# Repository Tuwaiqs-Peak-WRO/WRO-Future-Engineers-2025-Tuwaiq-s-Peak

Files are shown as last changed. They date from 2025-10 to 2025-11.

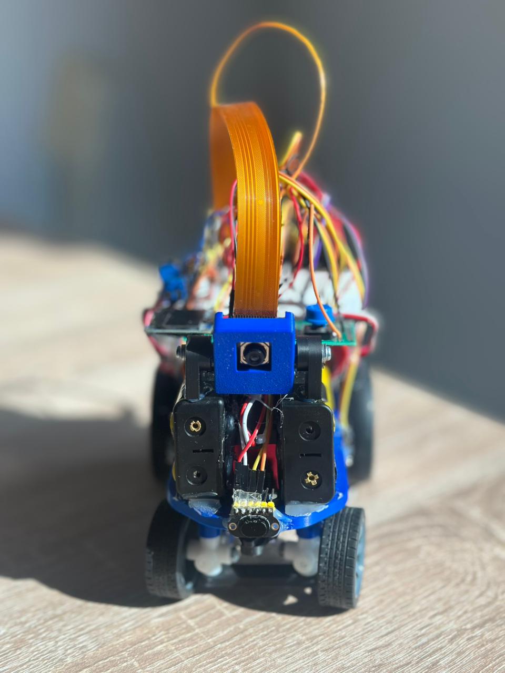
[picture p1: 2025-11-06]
Robot pictures/Robot Front.jpeg

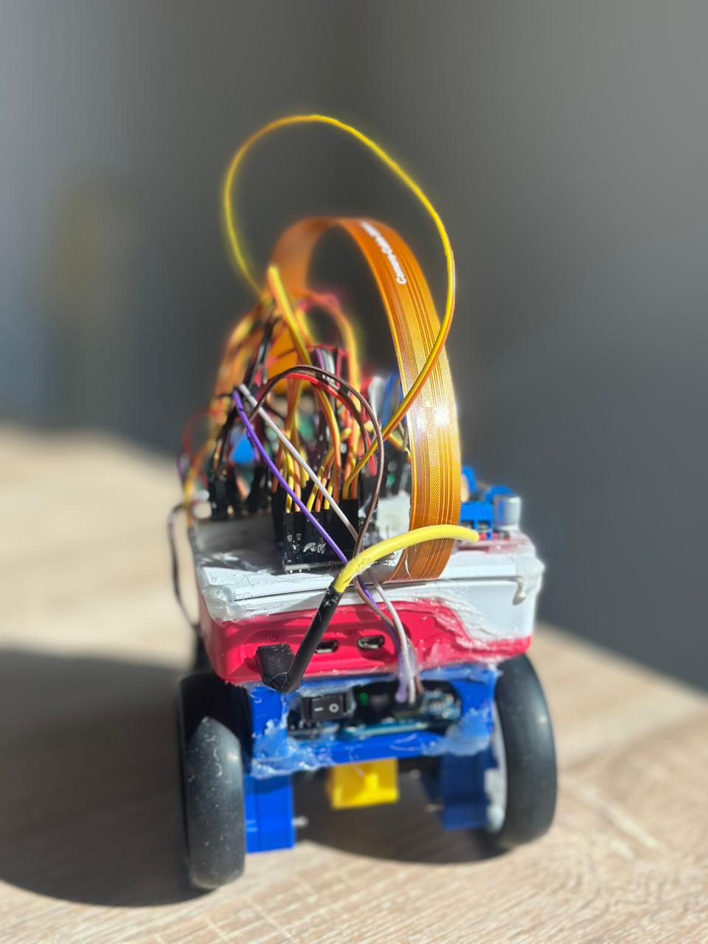
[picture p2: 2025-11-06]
Robot pictures/Robot Back.jpeg

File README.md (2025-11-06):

# Tuwaiqy – Autonomous Robot  
### by Team Tuwaiq’s Peak

WhatsApp Image 2025-10-19 at 17 24 52_02bfc6a8

---

## Team Members  
| Name | Role | Picture |
|---|---|---|
| Reda Mohammed Albin Ahmed| Coder, Strategic Designer | WhatsApp Image 2025-10-23 at 17 48 36_bcb1500e |
| Ibrahim Alangari | 3D Designer, Hardware Engineer | WhatsApp Image 2025-10-23 at 17 48 36_722a9d41 |

---

## Challenge Overview  
**Competition:** WRO Future Engineers  
**Goal:** Build a small autonomous car that can perceive, decide, and navigate without human input.  

### Objectives
- Lane keeping and path following  
- Traffic logic  
- Obstacle handling  
- Parking  

---

## System Overview  
Tuwaiqy uses a hybrid navigation and obstacle management system combining computer vision and Time-of-Flight (ToF) distance sensing.  
The camera provides visual awareness for lane and path detection, while the ToF sensor provides short-range precision distance data.  
Together, they allow the robot to follow the track, detect obstacles, and navigate autonomously in real time.  

---

## Hardware Components  

### 1. Raspberry Pi 5 


**Processor:** 64-bit Quad-core ARM Cortex-A76 @ 2.4 GHz  

**GPU:** VideoCore VII (dual 4K support)  

**Memory:** 8 GB LPDDR4X  

**Storage:** 32 GB microSD  

**Networking:** Gigabit Ethernet, Wi-Fi 5, Bluetooth 5.0  

**Ports:** 2 × USB 3.0, 2 × USB 2.0, 40-pin GPIO  

**Camera Interface:** 2 × CSI-2  

**Display:** 2 × micro-HDMI (4K 60 fps)  

**Power:** USB-C 5 V / 5 A  

**OS:** Raspberry Pi OS (64-bit)  

**Dimensions:** 85.6 × 56.5 × 17 mm (~50 g)  

**Advantages**
- High performance for AI and computer vision  
- Full Linux + Python environment  
- Compact and efficient  

**Disadvantages**
- Requires active cooling  
- Needs a stable 5 V / 5 A power source  

---

### 2. Raspberry Pi Active Cooler  
Screenshot 1447-05-04 at 10 58 43 AM

Compact fan-based cooler mounted via GPIO to prevent thermal throttling during high CPU usage.  

---

### 3. Gyroscope (BNO085)  
Screenshot 1447-05-04 at 10 59 45 AM

**Type:** 9-axis IMU (accelerometer + gyroscope + magnetometer)  

**Interface:** I²C / SPI  

**Voltage:** 3.3–5 V  

**Role:** Provides orientation and motion feedback for PID and steering control.  

---

### 4. OLED Display (0.96 in) 
Screenshot 1447-05-04 at 11 00 40 AM

**Resolution:** 128 × 64 pixels  

**Interface:** I²C / SPI  

**Voltage:** 3.3–5 V  

**Role:** Displays system information and debugging data.  

---

### 5. Push Button  
Screenshot 1447-05-04 at 11 03 05 AM

**Type:** Momentary (Normally Open)  

**Role:** Used for manual start or reset input.  

---

### 6. Raspberry Pi Camera Module 3 (Wide)  
Screenshot 1447-05-04 at 11 04 52 AM

**Resolution:** 12 MP  

**Video:** 1080p @ 60 fps  

**Interface:** CSI  

**Lens:** Fixed-focus wide-angle  

**Role:** Main vision system for lane detection and path recognition.  

---

### 7. Step-Up Converter (XL6019)  
Screenshot 1447-05-04 at 11 10 43 AM

**Input:** 5–32 V → **Output:** 5–35 V (adjustable)

**Output Current:** Up to 4 A

**Role:** Boosts voltage for servos or higher-load components.  

---

### 8. DC-DC Step Down Converter (Mini560)
Screenshot 1447-05-04 at 11 10 43 AM

**Output:** 3.3 / 5 / 9 / 12 V (adjustable)  

**Current:** Up to 8 A (>90 % efficiency)  

**Weight:** 7 g  

**Role:** Provides 5V power for the Raspberry Pi and logic circuits.  

---

### 9. (2x) NL1836HP battery
Screenshot 1447-05-04 at 10 59 45 AM

**Voltage:** 3.6 V

**Capacity:** 3600 mAh

**Discharge Rate:** 8 A (continuous)

**Type:** 18650 Li-ion rechargeable cell

**Role:** Provides high Current to power our motor

---

### 10. (2x) NITECORE NL1836 Battery
Screenshot 1447-05-04 at 10 59 45 AM

**Voltage:** 3.6 V 

**Capacity:** 3,600 mAh 

**Continuous Discharge Current:** 3 A 

**Role:** Reliable power source for the Raspperry pi 5

---

### 11. Servo Motor (40 kg·cm)  
Screenshot 1447-05-04 at 11 15 58 AM

**Voltage:** 6–12 V  

**Range:** 180°  

**Role:** Controls the steering of the front wheels.  

---

### 12. Servo Motor Driver (PCA9685PW)  
Screenshot 1447-05-04 at 11 17 08 AM

**Channels:** 16  

**Interface:** I²C  

**Voltage:** 5 V  

**Role:** Controls the steering servo and other PWM-based actuators.  

---

### 13. DC Motor with Encoder (620 RPM)  


**Voltage:** 12 V  

**Feedback:** Encoder output for speed monitoring  

**Role:** Rear-wheel drive and speed feedback for closed-loop control.  

---

### 14. IBT-4 DC Motor Driver 
Screenshot 1447-05-04 at 11 21 07 AM

**Voltage:** 5–36 V  

**Current:** Up to 43 A peak  

**Control:** PWM  

**Role:** Drives high-torque DC motors for movement.  

---

### 15. (2x) TOF200C-VL53L0X  
Screenshot 1447-05-04 at 11 22 43 AM

**Range:** Up to 2 m  

**Accuracy:** ±3 %  

**Interface:** I²C  

**Voltage:** 3.3V 

**Role:** Provides short-range distance on the right and on the left sides of the robot

---
### 16. TOF400C-VL53L1X
Screenshot 1447-05-04 at 11 22 43 AM

**Range:** Up to 4 m  

**Accuracy:** ±3 %  

**Interface:** I²C  

**Voltage:** 3.3V

**Role:** Provides long-range distance measurements for front obstacle detection and navigation.

---

### 17. TCA9548A 1-To-8 I2C 8 -Way Multi-Channel Expansion Board IIC Module Development Board
Screenshot 1447-05-04 at 11 22 43 AM

**Name:** TCA9548A 1-to-8 I²C Multiplexer

**Interface:** I²C  

**Voltage:** 1.65V – 5.5V

**Address Pins:** A0, A1, A2 (allow up to 8 multiplexers on the same I²C bus)

**Role:** Enables the use of multiple ToF sensors with identical I²C addresses for multi-directional distance measurement on our Robot.

---

## System Integration  

**Power**
- Nihewo 7.4 V battery powers the system.  
- Mini560 converter outputs regulated 5 V for logic and control circuits.  
- XL6019 step-up converter provides higher voltage for servo operation.  

**Control**
- Raspberry Pi 5 handles computer vision and sensor fusion.  
- BNO085 IMU provides stabilization data.  
- TOF sensor measures distance for real-time obstacle management.  

**Motion**
- IBT-4 driver powers the rear DC motors.  
- PCA9685 controls the front steering servo.  
- Encoders provide feedback for accurate speed control.  

**Feedback**
- OLED display shows live data and status.  
- RGB LED and Buzzer provide visual and audio feedback.  
- Push Button allows manual start or reset.  

---

## System Flow  

```text
Camera + TOF Sensor
        ↓
    Raspberry Pi 5
        ↓
 PCA9685 → Servo (Steering)
 IBT-4 → DC Motors (Drive)
        ↓
 OLED + RGB LED + Buzzer (Feedback)
        ↓
 Power Distribution → Mini560 / XL6019 from 7.4 V Battery

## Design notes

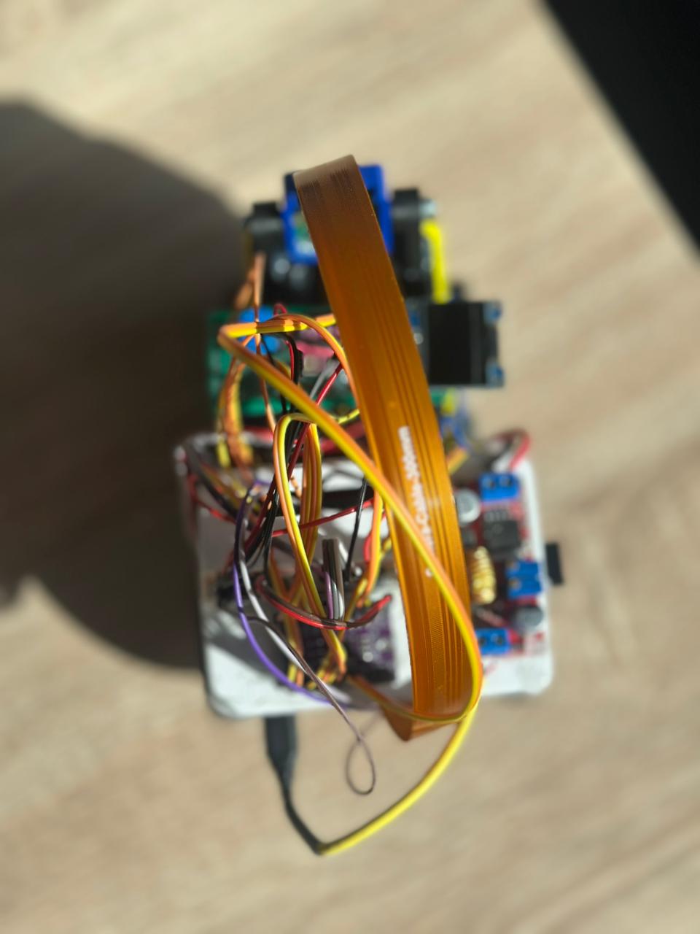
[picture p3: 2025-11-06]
Robot pictures/Robot Top.jpeg

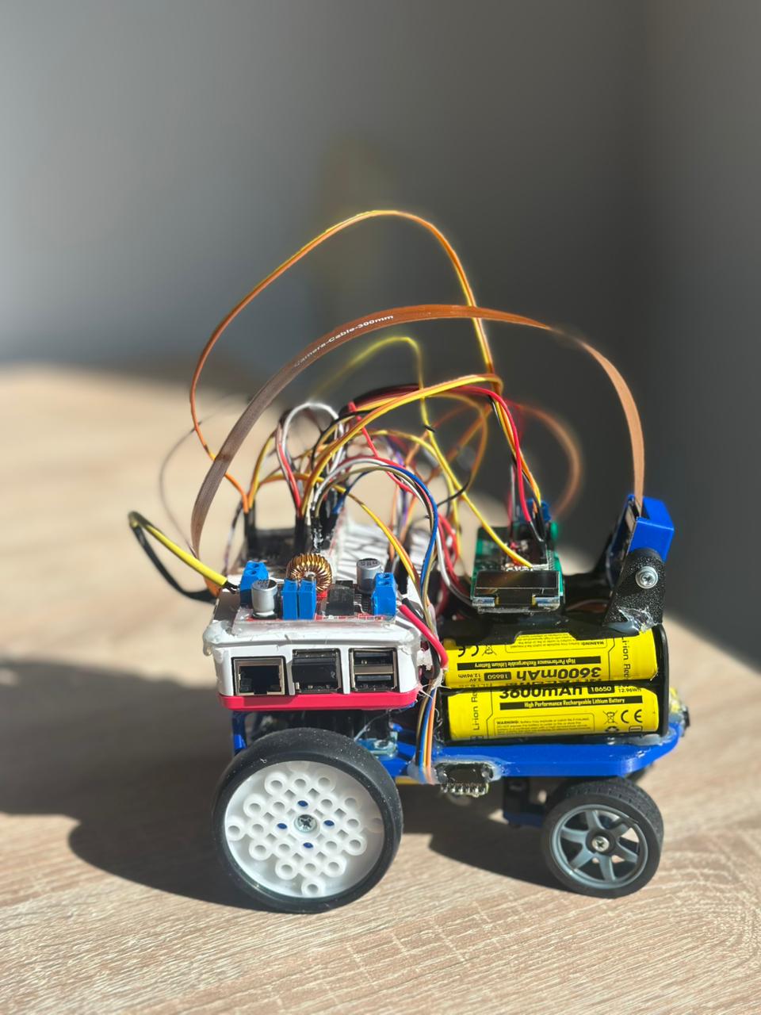
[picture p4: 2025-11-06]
Robot pictures/Robot Right.jpeg

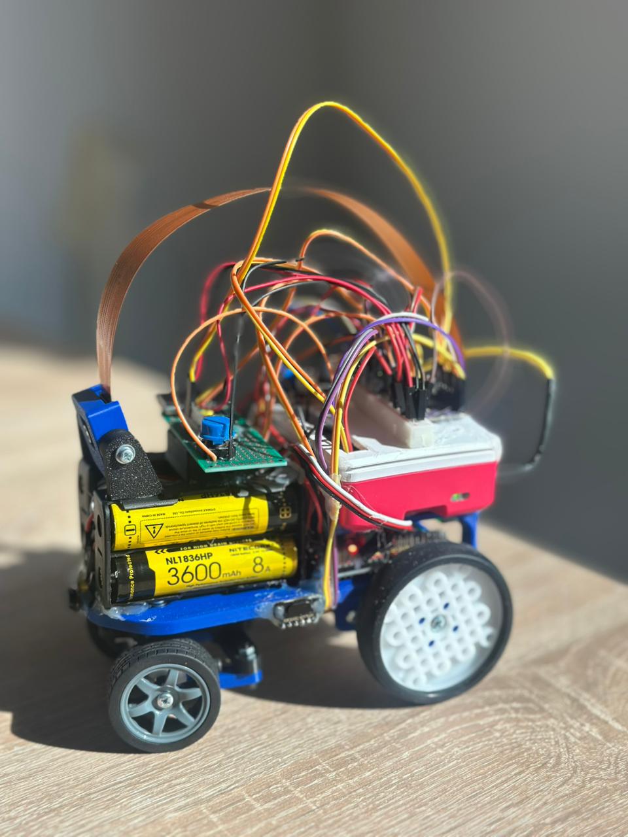
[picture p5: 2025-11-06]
Robot pictures/Robot Left.jpeg

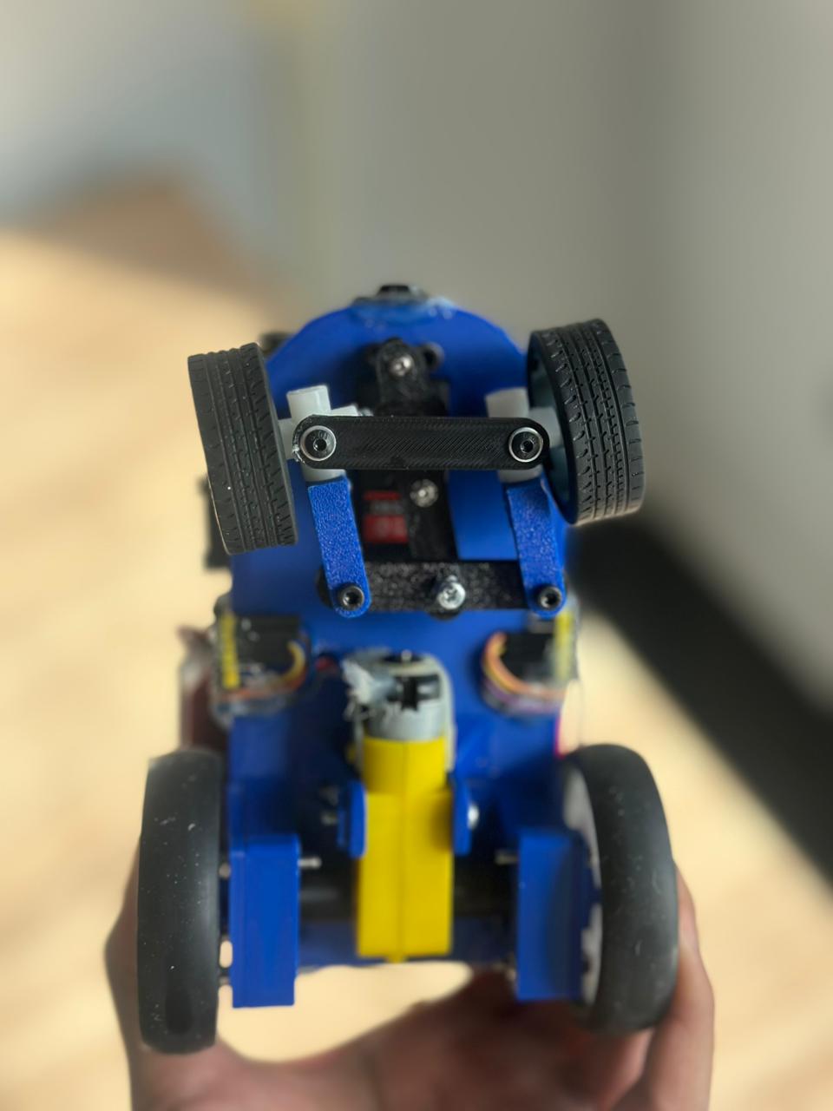
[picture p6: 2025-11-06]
Robot pictures/Robot Bottom.jpeg

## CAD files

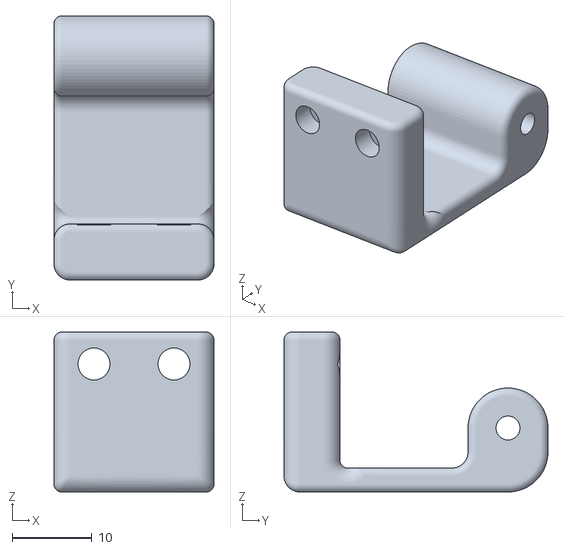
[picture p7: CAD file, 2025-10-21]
3d models/cam 1-30mm.stl
20.0 x 33.0 x 20.0

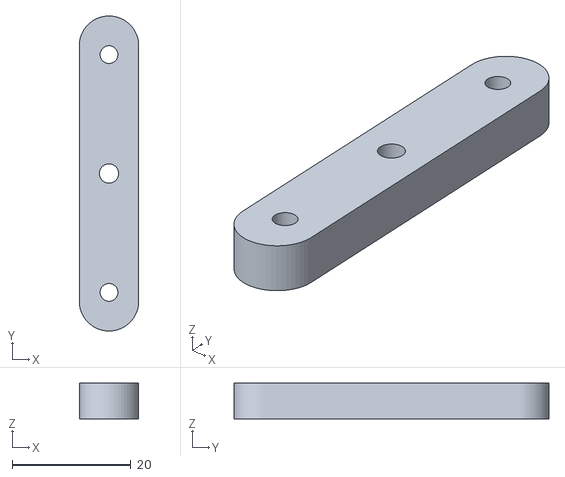
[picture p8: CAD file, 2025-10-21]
3d models/steering p4.stl
10.0 x 53.0 x 6.00

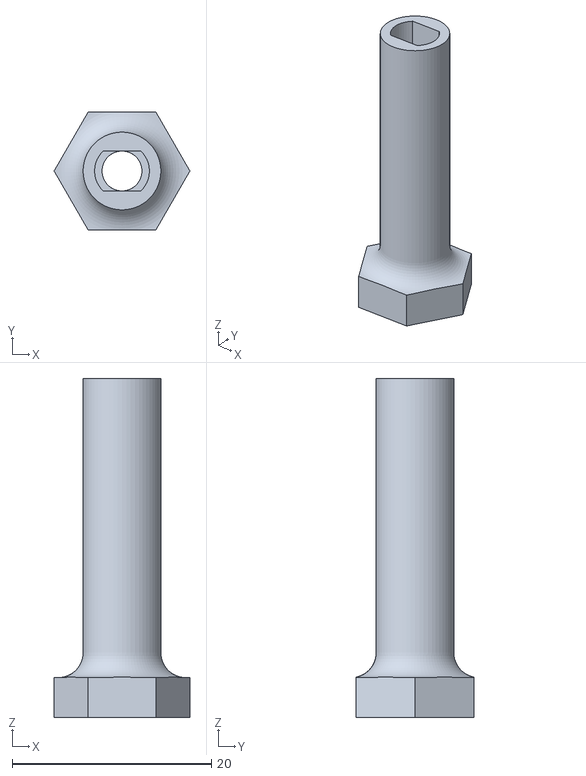
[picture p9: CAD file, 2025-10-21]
3d models/wheel shaft.stl
13.6 x 11.8 x 34.0

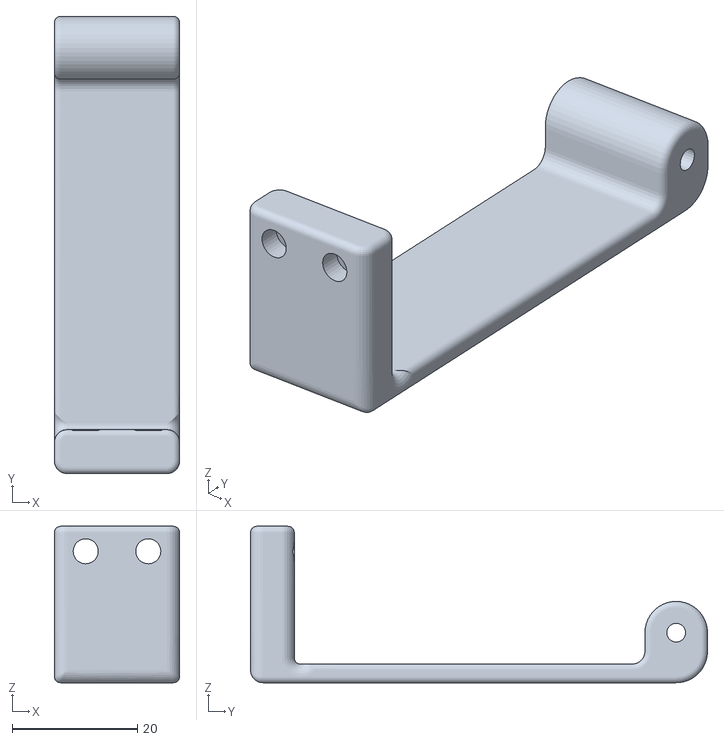
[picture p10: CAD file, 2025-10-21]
3d models/cam 1.2.stl
20.0 x 73.0 x 25.0

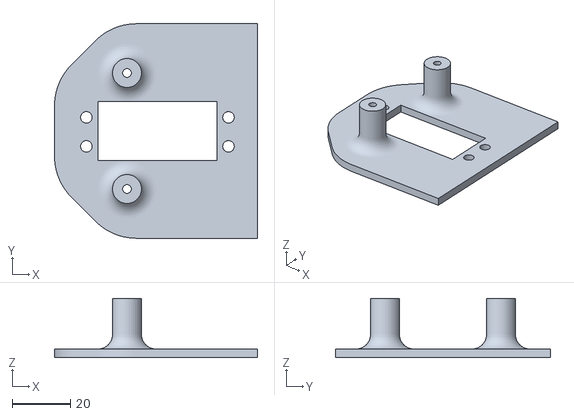
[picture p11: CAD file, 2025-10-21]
3d models/base_test.stl
70.0 x 74.0 x 20.5

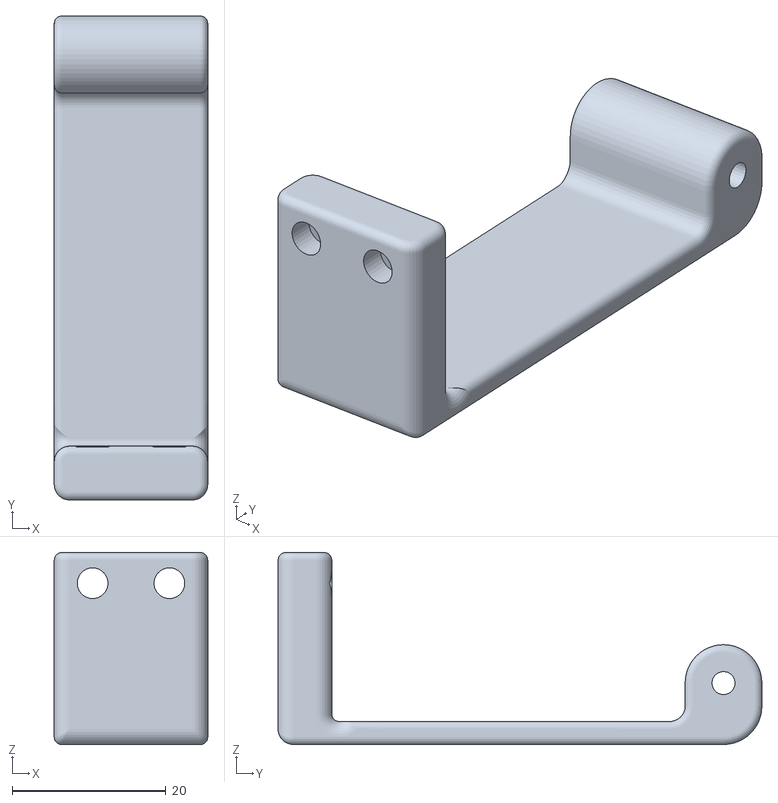
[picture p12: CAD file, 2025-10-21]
3d models/cam 1.3.stl
20.0 x 63.0 x 25.0

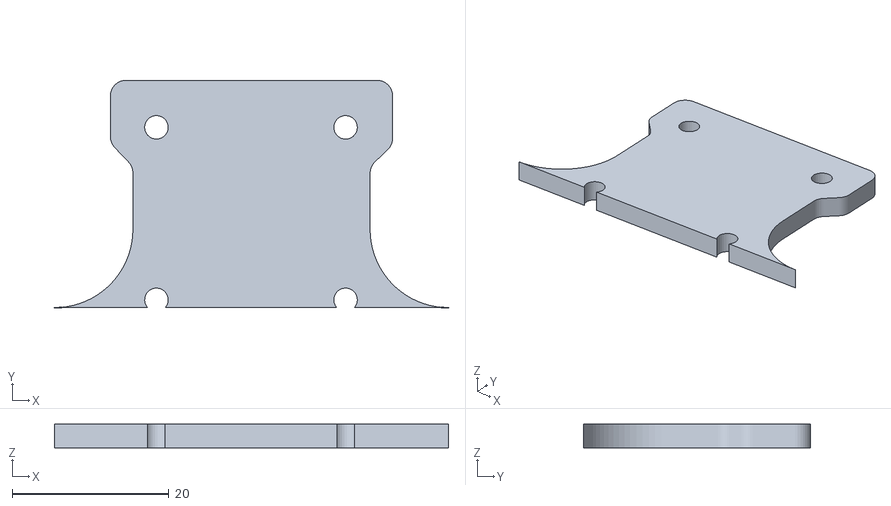
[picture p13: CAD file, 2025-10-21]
3d models/bearing case.stl
50.2 x 29.0 x 3.00

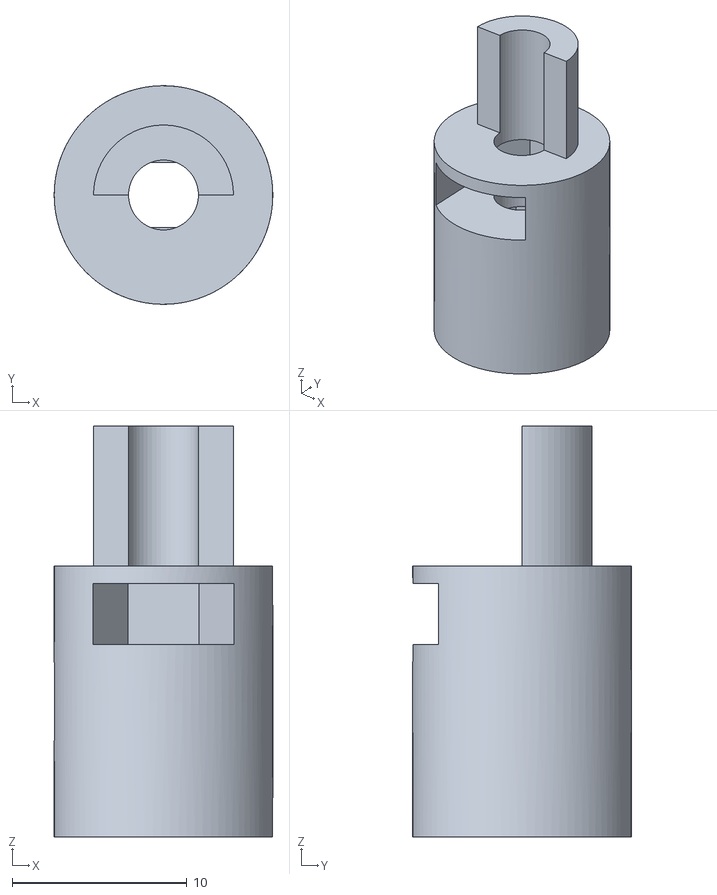
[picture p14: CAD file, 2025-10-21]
3d models/wheel to motor 1.stl
12.5 x 12.5 x 23.5

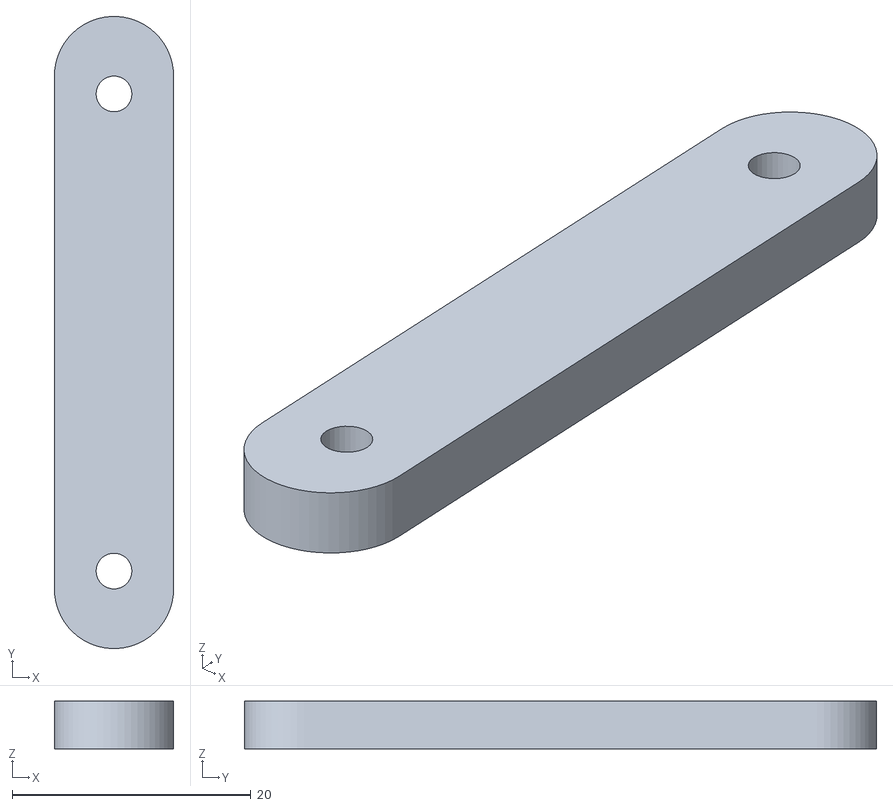
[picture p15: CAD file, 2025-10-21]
3d models/steering p1.stl
10.0 x 53.0 x 4.00

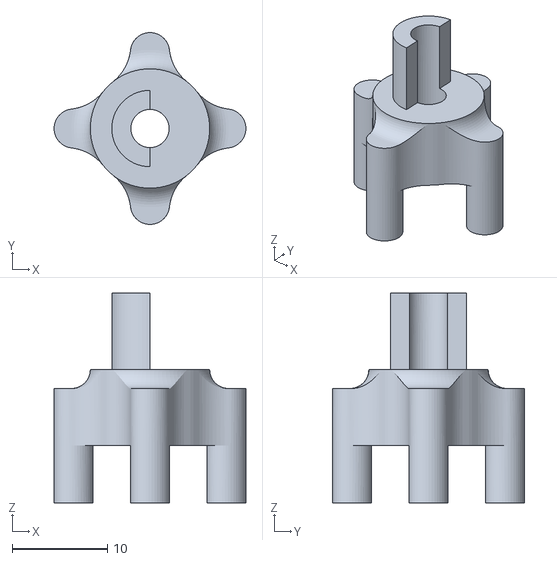
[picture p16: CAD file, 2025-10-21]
3d models/wheel to motor 2.2.stl
20.1 x 20.1 x 22.0

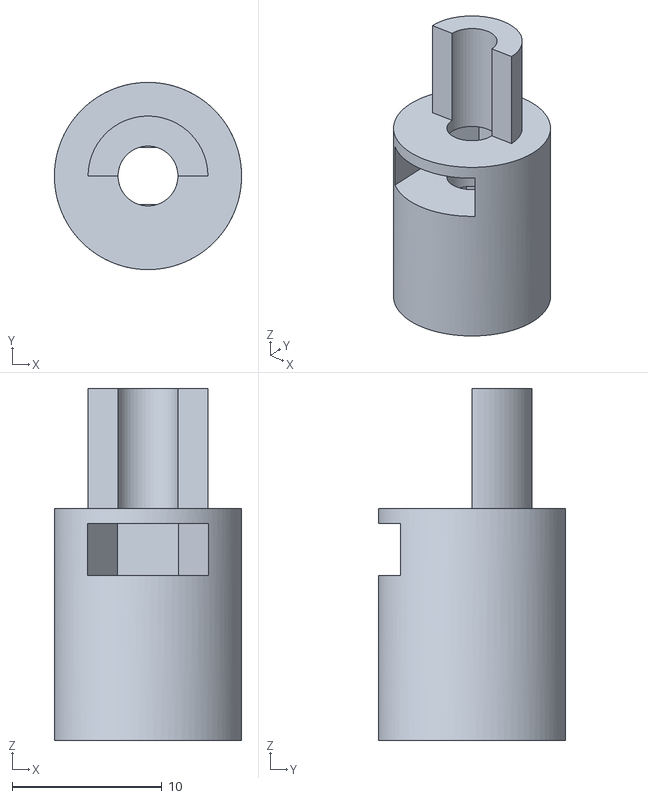
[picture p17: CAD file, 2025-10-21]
3d models/wheel to motor 1.1.stl
12.5 x 12.5 x 23.5

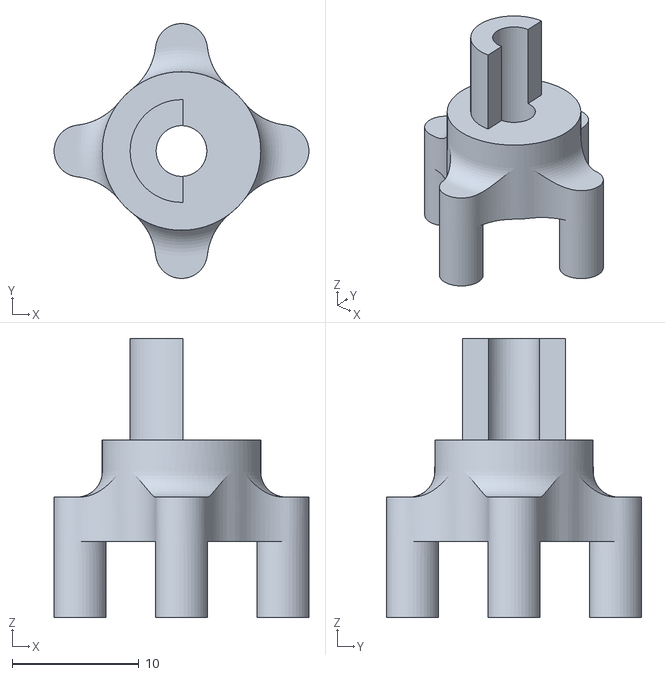
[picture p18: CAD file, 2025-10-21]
3d models/wheel to motor 2.stl
20.1 x 20.1 x 22.0

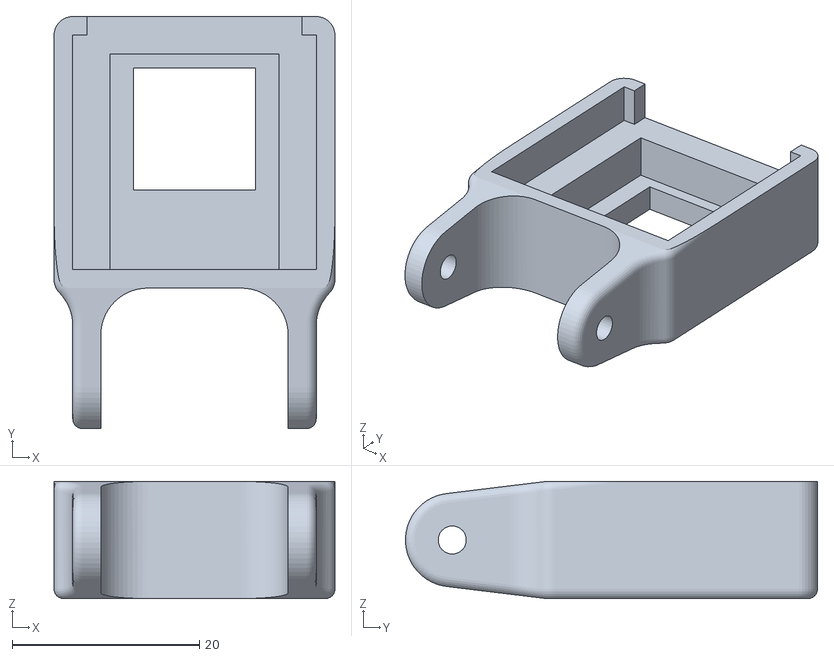
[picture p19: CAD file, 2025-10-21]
3d models/cam 3_RAS.stl
30.0 x 44.0 x 12.5

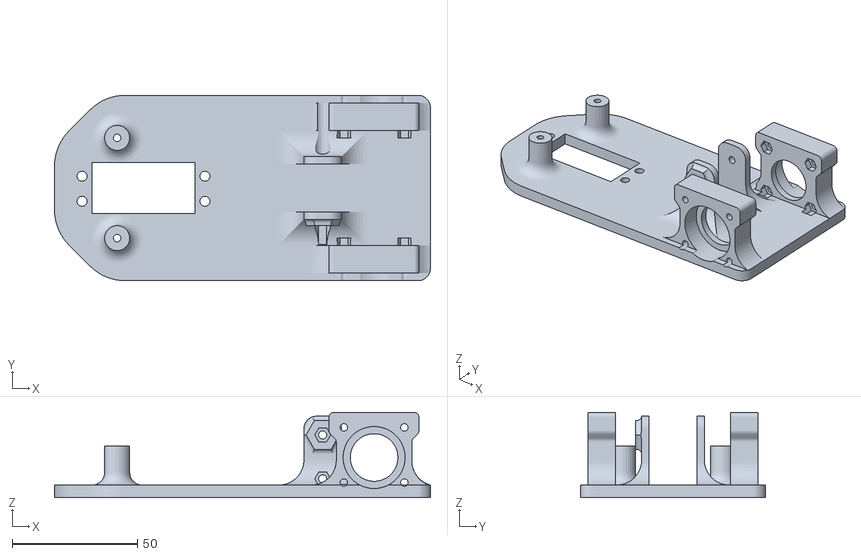
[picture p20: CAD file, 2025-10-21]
3d models/base.stl
150.0 x 74.0 x 34.0

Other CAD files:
3d models/cam 1.1.stl
3d models/base 1.0.stl
3d models/step_dow_case.stl
3d models/base 1.1.stl
3d models/base1.2.stl
3d models/bearing case 1.stl
3d models/cam 1-40.stl
3d models/cam 1.stl
3d models/cam 2.1.stl
3d models/cam 2.stl
3d models/plate_battery.stl
3d models/steering p2.stl
3d models/steering p3.stl
3d models/wheel shaft.1.stl
3d models/wheel to motor 1.2.stl
3d models/wheel to motor 2.1.stl
3d models/wheel to motor 2.3.stl

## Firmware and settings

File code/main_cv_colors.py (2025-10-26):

import cv2
import numpy as np
from picamera2 import Picamera2
from process_frames_colors import *
from motor_controller import create_dc_motor
from servo_controller import create_servo
from BnoSensor_controller import creat_bno_sensor
import collections
import adafruit_vl53l0x
import board
from oledInfo import *

i2c = board.I2C()
tof_sensor = adafruit_vl53l0x.VL53L0X(i2c)

import time

DEFAULT_SPEED = 0.35
DEFAULT_REVERSE_SPEED = 0.3

motor = create_dc_motor()
servo = create_servo(channel=0, max_pulse=2500, min_pulse=500, reverse_angle=True,center_fix = 6, max_angle=30)
bno = creat_bno_sensor()

def _get_raw_rc_angle(bno):
        """Get current raw angle from sensor."""
        sensor_data = bno.get_sensor_data()
        if not sensor_data:
            print("no gyro data")
            return None
        yaw_angle_raw = sensor_data['gyro_angles'][2]
        yaw_angle_raw
        return yaw_angle_raw

def get_rc_angle(bno):
        yaw_angle = _get_raw_rc_angle(bno)
        yaw_angle = np.degrees(yaw_angle)
        yaw_angle = (yaw_angle + 180) % 360 - 180
        return yaw_angle

class stuck_checker:
    def __init__(self):
         pass
         self.currTime = time.time()
         self.similarity_start_time = 0
         self.previous_frame = None
    def frames_are_similar(self, frame1, frame2, threshold):
        if frame1 is None or frame2 is None:
            return False
        # Convert to grayscale for simpler comparison
        gray1 = cv2.cvtColor(frame1, cv2.COLOR_BGR2GRAY)
        gray2 = cv2.cvtColor(frame2, cv2.COLOR_BGR2GRAY)

        # Compute structural similarity
        difference = cv2.absdiff(gray1, gray2)
        _, diff_thresh = cv2.threshold(difference, 25, 255, cv2.THRESH_BINARY)

        # Calculate the ratio of non-difference pixels
        non_zero_count = np.count_nonzero(diff_thresh)
        total_pixels = frame1.shape[0] * frame1.shape[1]
        similarity_ratio = (total_pixels - non_zero_count) / total_pixels

        return similarity_ratio >= threshold
    
    def check_if_stuck( self, frame, similarity_threshold = 0.9, similarity_duration = 3):
        # Check for frame similarity over time (car is stuck)
        # print('in check')
        self.currTime = time.time()
        if self.previous_frame is None:
             self.previous_frame = frame.copy()
             return False
        
        # print("HHHHH")
        if self.frames_are_similar(self.previous_frame, frame, threshold=similarity_threshold):
            if self.similarity_start_time == 0:
                self.similarity_start_time = self.currTime
            elif self.currTime - self.similarity_start_time >= similarity_duration :
                print("stuck")
                
                self.similarity_start_time = 0  # Reset the timer
                return True
            else:
                pass
                # print("checking stuck..")
        else:
            # Reset similarity timer if the frames are not similar
            self.similarity_start_time = 0
            self.previous_frame = frame.copy()
            return False
        
    

def main():

    servo.center()
    initial_point = -1
    initial_angle = 0
    prev_wall_point = -1
    counter = 0
    prev_time_counter = time.time()
    prev_time_SteerLock = time.time()
    lab_count = 0
    start_counter = True
    num_points_avg = 60 # How many points from the trace to avg (magic number)
    steerLock_duration = 0
    stuck_checker_obj = stuck_checker()
    steer_angle = 0
    steer_angle_buffer = collections.deque(maxlen=3) #Increase this for smoother steering but too much will cause some steer delay
    run_speed = DEFAULT_SPEED
    def_offset_fix_factor =0
    offset_fix_factor = def_offset_fix_factor # to compensate quircky track , rais above 0 if bad ccw and lower for bad cw
    max_offset = 40
    cw = None
    last_obs_before_revere = ""
    try:
        while True:
            front_dist = tof_sensor.range
            rc_angle = get_rc_angle(bno)
            
            curr_time = time.time()
            frame = picam2.capture_array()
            
            offset_steer, wall_point, comp_img, flag = process_frame(frame.copy(), num_points_avg)
            
            has_display = True
            if os.environ.get('DISPLAY') is None:
                has_display = False

            if has_display:
                cv2.imshow("preview", comp_img)
                if cv2.waitKey(1) & 0xFF == ord('q'):
                    break
            
                 
            if steerLock_duration:
                 if curr_time - prev_time_SteerLock < steerLock_duration:
                    continue 
                 else:
                    motor.set_speed(0)
                    steerLock_duration = 0
            
            if stuck_checker_obj.check_if_stuck(frame) or front_dist < 100:
                print(f"backward at front dist {front_dist}")
                prev_time_counter = curr_time
                steerLock_duration = 1.5 #seconds to go backward
                prev_time_SteerLock = curr_time
                
                if cw is None:
                    smoothed_steering_angle  = sum(steer_angle_buffer)/len(steer_angle_buffer)
                    steer_angle = -smoothed_steering_angle * 0.8
                else:
                    steer_angle = 20 if cw else -20
                servo.set_angle(steer_angle)
                if run_speed:
                    motor.set_speed(-DEFAULT_REVERSE_SPEED)
                continue
            if len(flag):
                # print(flag)
                if "obs" in flag:
                    # max_offset = 20
                    run_speed = 0.3
                    offset_fix_factor = 0

                    if "obs clearance" in flag:

                        if -10 < rc_angle * (1 if cw else -1) < 100 and counter==1:
                            if "red" in flag:
                                last_obs_before_revere = "red"
                            elif "green" in flag:
                                last_obs_before_revere = "green"
                            # print("reverse nowwwwwww")
                        #flip cw
                        # cw = not cw
                        # # # hard steer to right
                        # steer_angle = servo.max_angle
                        # servo.set_angle(steer_angle)
                        # run_speed = 0.3
                        # motor.set_speed(run_speed)
                        # #reinitial angle
                        # initial_angle = 180
                        # steerLock_duration = 1.5
                        # continue

            else:
                if front_dist < 200:
                    # print('hard steer')
                    steerLock_duration = 1
                    run_speed = 0.3
                    steer_angle = -servo.max_angle if cw else servo.max_angle
                    servo.set_angle(steer_angle)
                    if run_speed:
                        motor.set_speed(run_speed)
                    continue
                else:
                    max_offset = 40
                    offset_fix_factor = def_offset_fix_factor
                    run_speed = DEFAULT_SPEED
           
            # if cw is not None:
            #     offset_steer += -offset_fix_factor if cw else offset_fix_factor
            offset_steer = min(max_offset, max(-max_offset, offset_steer))
            steer_ratio = offset_steer / max_offset
            steer_angle = int(steer_ratio*servo.max_angle)
            steer_angle_buffer.append(steer_angle)
            smoothed_steering_angle  = sum(steer_angle_buffer)/len(steer_angle_buffer)
            
            servo.set_angle(smoothed_steering_angle)
            # print("rc angle:",rc_angle)
            if cw is None:
                # if smoothed_steering_angle >= servo.max_angle*0.8:
                if rc_angle > 80:
                    print("round is ccw")
                    cw = False
                # elif smoothed_steering_angle <= -servo.max_angle*0.8:
                elif rc_angle < -80:
                    print("round is cw")
                    cw = True
            motor.set_speed(run_speed)
            
            #counting labs section
            if wall_point is not None:
                if initial_point < 0 and wall_point[1] < 35:
                        prev_time_counter = curr_time
                        initial_point = wall_point[1]
                        # initial_point = front_dist
                        initial_angle = 0
                        # prev_wall_point = 1000
                        print(initial_point)
                if curr_time - prev_time_counter > 10:
                    # print(rc_angle)
                    if abs(abs(rc_angle)-initial_angle) < 15 :
                        # print(wall_point)
                        # if wall_point[1] > 30:
                        print("angle at count section:",rc_angle)
                        print("midpoint white pixels:",wall_point[1])
                        # print("dist at count s8ection:", front_dist)
                        # if (abs(initial_point - front_dist) < 20):
                        if (wall_point[1] >= initial_point ):
                            if start_counter:
                                counter+=1
                                print("counter: ", counter)
                                if counter and last_obs_before_revere == "red":
                                    print("reverse nowwwwwww")
                                if counter == 3:
                                    motor.set_speed(-0.1)#brakes
                                    time.sleep(0.2)
                                    break
                                prev_time_counter = curr_time

                            start_counter = False
                        prev_wall_point = front_dist
                    else:
                         start_counter = True
                         prev_wall_point = 0
                    
        
    finally:
        picam2.stop()
        cv2.destroyAllWindows()
        servo.center()
        servo.unlock()
        motor.stop()
        


ip_address = get_local_ip()
oled.display_info([ip_address,"Obistcale"])

has_display = True
if os.environ.get('DISPLAY') is None:
    has_display = False


if __name__ == "__main__":
    if not has_display:
        while(not button.is_pressed):
            k = 1
    button.close()

    try:
        # Initialize Picamera2
        picam2 = Picamera2()
        RESIZE_FACTOR = 1
        # picam2.sensor_mode = 4
        #2304 x 1296-PC1B
        cam_res = (2304 // RESIZE_FACTOR, 1296 // RESIZE_FACTOR)

        video_config = picam2.create_video_configuration(raw={"size": cam_res, "format" : 'SGBRG10'}, main = {"size":(2304//10, 1296//10)})
        picam2.configure(video_config)
        picam2.start()

        load_hsv_from_json()
        main()
    except Exception as e:
        print(f"An error occurred: {e}")
        picam2.stop()
        cv2.destroyAllWindows()
        servo.center()
        time.sleep(2)
        servo.unlock()
        motor.stop()
    finally:
        picam2.stop()
        cv2.destroyAllWindows()
        servo.center()
        time.sleep(2)
        servo.unlock()
        motor.stop()

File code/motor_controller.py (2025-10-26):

from gpiozero import PWMOutputDevice, Buzzer,DigitalOutputDevice

buzzer = Buzzer(23)
class DCMotorController:
    def __init__(self, forward_pin=17, reverse_pin=27,servo_oe_pin = 10):
        self.motor_forward = PWMOutputDevice(forward_pin)
        self.motor_reverse = PWMOutputDevice(reverse_pin)
        self.oe_pin = DigitalOutputDevice(servo_oe_pin, active_high=True, initial_value=False)
        

    def set_speed(self, speed):
        """
        Set the motor speed and direction.
        :param speed: Float between -1 and 1. Negative for reverse, positive for forward.
        """
        if speed < -1 or speed > 1:
            raise ValueError("Speed must be between -1 and 1")

        if speed < 0:
            self.motor_forward.value = -speed
            self.motor_reverse.off()
        elif speed > 0:
            self.motor_reverse.value = speed
            self.motor_forward.off()
        else:
            self.motor_forward.off()
            self.motor_reverse.off()

    def stop(self):
        """Stop the motor."""
        self.motor_forward.off()
        self.motor_reverse.off()

    def disable_servo(self):
        """Disable servo outputs using OE pin"""
        self.oe_pin.on()  # Set HIGH to disable
        print("Servo outputs disabled")  # Debug message
        
    def enable_servo(self):
        """Enable servo outputs using OE pin"""
        self.oe_pin.off()  # Set LOW to enable
        print("Servo outputs enabled")  # Debug message
        
    def cleanup(self):
        """Clean up GPIO resources"""
        try:
            self.stop()
            self.disable_servo()
            self.motor_forward.close()
            self.motor_reverse.close()
            self.oe_pin.close()
        except:
            pass
        


    @staticmethod
    def buzzer_on():
        buzzer.on()
   
    @staticmethod
    def buzzer_off():
        buzzer.off()

def create_dc_motor(forward_pin=17, reverse_pin=27, servo_oe_pin=10):
    """Create and return a DCMotorController instance."""
    return DCMotorController(forward_pin, reverse_pin, servo_oe_pin)

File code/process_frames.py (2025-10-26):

import cv2
import numpy as np
from picamera2 import Picamera2


def display_live_window(image, window_name="Live Tracking"):
    """Utility function to display images in OpenCV window."""
    cv2.imshow(window_name, image)
    cv2.waitKey(1)  # 1 ms wait to allow OpenCV to process the window

def find_bottommost_contour(contours, image_height):
    """
    Find the contour closest to the bottom of the image.

    :param contours: List of contours.
    :param image_height: Height of the image.
    :return: The contour closest to the bottom.
    """
    max_bottom = 0
    bottommost_contour = None

    for contour in contours:
        # Find the bottommost point of the contour
        bottom_point = max(contour, key=lambda point: point[0][1])
        bottom_y = bottom_point[0][1]
        
        # Update the closest contour if this one is lower
        if bottom_y > max_bottom:
            max_bottom = bottom_y
            bottommost_contour = contour

    return bottommost_contour
def generate_path(filtered_track):
    """
    Generate a path based on the centerline of the filtered track.

    :param filtered_track: Binary image with the track in white pixels.
    :return: Path points [(x1, y1), (x2, y2), ...].
    """
    height, width = filtered_track.shape
    path_points = []

    for y in range(height):
        # Find white pixels in the current row
        white_pixels = np.where(filtered_track[y, :] == 255)[0]
        if len(white_pixels) > 50:
            # Calculate the midpoint of the white pixels
            center_x = (white_pixels[0] + white_pixels[-1]) // 2
            path_points.append((center_x, y))

    return np.array(path_points)

def filter_path_points(path_points, smoothing_window=5, deviation_threshold=20):
    """
    Filter noisy path points using smoothing and deviation filtering.

    :param path_points: Array of (x, y) path points.
    :param smoothing_window: Size of the moving average smoothing window.
    :param deviation_threshold: Maximum allowable deviation from the fitted path.
    :return: Filtered path points.
    """
    np.array(path_points)
    # Separate x and y coordinates
    x_values = path_points[:, 0]
    y_values = path_points[:, 1]

    # Step 1: Moving Average Smoothing
    smooth_x_values = np.convolve(
        x_values, np.ones(smoothing_window) / smoothing_window, mode="same"
    )

    # Step 2: Fit a polynomial to the smoothed points
    fit = np.polyfit(y_values, smooth_x_values, deg=2)  # Quadratic fit
    fitted_x_values = np.polyval(fit, y_values)

    # Step 3: Remove points with large deviations
    deviations = np.abs(x_values - fitted_x_values)
    filtered_indices = deviations < deviation_threshold
    filtered_path_points = path_points[filtered_indices]

    return filtered_path_points

def process_frame(frame, num_points_avg):
    original = cv2.cvtColor(frame, cv2.COLOR_BGR2RGB)  # Convert to RGB for plt
    gray = cv2.cvtColor(frame, cv2.COLOR_BGR2GRAY)
    # Step 2: Filter Black Walls and Highlight White Track
    gray = cv2.GaussianBlur(gray, ksize=(5,5), sigmaX=10)
    _, white_mask = cv2.threshold(gray, 80, 255, cv2.THRESH_BINARY)  # White track
    _, black_mask = cv2.threshold(gray, 100, 255, cv2.THRESH_BINARY_INV)  # Black walls
    height, width = gray.shape

    inverted_black_mask = 255-np.array(black_mask)
    filtered_track = np.zeros_like(gray)
    contours, _ = cv2.findContours(white_mask, cv2.RETR_EXTERNAL, cv2.CHAIN_APPROX_SIMPLE)
    # contours, _ = cv2.findContours(inverted_black_mask, cv2.RETR_EXTERNAL, cv2.CHAIN_APPROX_SIMPLE)
    if(len(contours)):
        largest_contour_index = max(range(len(contours)), key=
        lambda i: cv2.contourArea(contours[i]))
        
        cv2.drawContours(filtered_track, contours, largest_contour_index, 255, thickness=cv2.FILLED)
    # Get the middle column of the image
    middle_x = width // 2
    middle_column = filtered_track[:, middle_x]

    # Find indices where the pixel value is white (255)
    white_indices = np.where(middle_column == 255)[0]
    wall_point = None
    if white_indices.size > 0:
        # Get the lowest y-value (maximum index since y increases downward in images)
        lowest_y = white_indices[0]
        wall_point = (middle_x, lowest_y)
        # print(f"Lowest black point in the middle column: {wall_point}")
    else:
        print("No black pixels found in the middle column.")
    roi = np.zeros_like(gray)
    lower_region = int(height * 0.17)  # Adjust the starting point of the lower ROI
    higher_region = int(height * 0.5)
    roi[lower_region:higher_region, :] = 255  # Keep only the lower region
    filtered_track = cv2.bitwise_and(filtered_track, roi)
    # Iterate through each column
    # for x in range(width):
    #     # Flag to indicate if a black pixel has been encountered in the column
    #     black_found = False
    #     for y in range(int(height*0.2),height):
    #         if filtered_track[y, x] == 0:  # Black pixel encountered
    #             black_found = True
    #             break
    #         else:
    #             # Black out the current pixel in the white mask
    #             filtered_track[y, x] = 0    
    
    path_points = generate_path(filtered_track)
    try:
        pass
        path_points = filter_path_points(path_points, smoothing_window=5, deviation_threshold=20) 
    except:
        pass

    for i in range(len(path_points) - 1):
        cv2.line(original, path_points[i], path_points[i + 1], (255, 0, 0), 2)

    try:
        offset_steer =  width//2 - int(np.mean(path_points[-min(num_points_avg, len(path_points)): ,0]))
        # if start_path_point > height//2:
        #     # offset_steer = path_points[path_points[:,1]==77][0][0] - path_points[path_points[:,1]==50][0][0]
        # else:
        #     offset_steer = 0
    except:
        offset_steer = 0
    # print(offset_steer)

    cv2.line(original, 
            (width//2, height), 
            (width//2 - offset_steer, height*3//4), 
            (0,255,0), 2)  # Path line
    
    filtered_track_rgb = cv2.cvtColor(filtered_track, cv2.COLOR_GRAY2RGB)
    # Display all images in OpenCV window
    combined_image = np.hstack([original, filtered_track_rgb])
    # display_live_window(combined_image)
    return offset_steer, wall_point, combined_image
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

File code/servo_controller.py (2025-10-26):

import time
from adafruit_pca9685 import PCA9685
from board import SCL, SDA
import busio




class ServoController:
    def __init__(self, channel=0, min_pulse=1000, max_pulse=2000, reverse_angle = False,center_fix = 6, max_angle = 90):
        # Initialize I2C bus and PCA9685
        self.i2c = busio.I2C(SCL, SDA)
        self.pca = PCA9685(self.i2c)
        self.pca.frequency = 50  # Set frequency to 50Hz for servos
        self.center_fix = center_fix
        # Set up the servo
        self.max_angle = max_angle
        self.servo = self.pca.channels[channel]
        self.min_pulse = min_pulse
        self.max_pulse = max_pulse
        self.reverse_factor = -1 if reverse_angle else 1
    def set_angle(self, angle):
        """Set the servo to a specific angle (-90 to 90 degrees)."""
        angle += self.center_fix
        if -90 <= angle <= 90:
            pulse_width = self.min_pulse + (self.max_pulse - self.min_pulse) * ((self.reverse_factor*angle + 90) / 180)
            self.servo.duty_cycle = int(pulse_width * 0xFFFF / 20000)
        else:
            raise ValueError("Angle must be between -90 and 90 degrees")

    def sweep(self, start=-90, end=90, step=5, delay=0.1):
        """Perform a sweep from start to end angle."""
        for angle in range(start, end + 1, step):
            self.set_angle(angle)
            time.sleep(delay)

    def center(self):
        """Center the servo (set to 0 degrees)."""
        self.set_angle(0)
    def unlock(self):
        self.i2c.unlock()

def create_servo(channel=0, min_pulse=1000, max_pulse=2000, reverse_angle= False,center_fix = 6, max_angle = 90):
    """Create and return a ServoController instance."""
    return ServoController(channel, min_pulse, max_pulse, reverse_angle,center_fix, max_angle)
